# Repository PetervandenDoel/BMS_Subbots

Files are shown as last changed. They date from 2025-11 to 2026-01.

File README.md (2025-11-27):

# Battery Management System (BMS) for UBC Subbots

Custom 4-cell LiPo Battery Management System designed for the Subbots AUV.
Supports high-current discharge, full battery protection, and regulated power distribution for onboard electronics.

⸻

## Overview
	•	Designed for a 4S LiPo (Blue Robotics)
	•	Nominal: 14.8 V
	•	Max: 16.8 V
	•	Supports up to 80 A peak discharge
	•	Uses BQ76920 as the analog front end (AFE)
	•	Uses nRF54L15 as the microcontroller
	•	Generates regulated 12 V, 9 V, and 5 V rails using high-current buck regulators
	•	Low-side FET switching for discharge control
	•	Complete cell balancing, protection, and monitoring

⸻

### Battery Front End (BQ76920)
	•	Measures cell voltages (4S)
	•	Computes pack current using a Kelvin-routed shunt resistor
	•	Provides:
	•	Over-current (OCD) protection
	•	Short-circuit (SCD) protection
	•	Under-voltage and over-voltage protection
	•	Temperature monitoring (TS1)
	•	Cell balancing
	•	SRP/SRN routed as Kelvin sense lines with RC filtering
	•	PACK− and BAT− separated through the shunt resistor only

⸻

### Microcontroller (nRF54L15)
	•	Handles I²C communication with BQ76920
	•	ALERT pin used for interrupt-based event handling
	•	SWD interface exposed
	•	Powered from the regulated 3.3 V rail

⸻

## Power Regulation

### LM2596 (Pre-Regulator)
	•	Drops pack voltage down to ~5 V
	•	Used strictly to power the logic and control section of the AOZ2261NQI-11 regulators

### AOZ2261NQI-11 Buck Regulators
	•	Three independent outputs:
	•	12 V rail
	•	9 V rail
	•	5 V rail
	•	Each regulator includes:
	•	Separate AGND and PGND regions
	•	A single-point net tie back to PACK−
	•	Recommended output LC filtering
	•	Local decoupling at the VCC pin
	•	Designed to supply high peak currents needed by the AUV subsystems

⸻

## Grounding Strategy
	•	PACK− is the main high-current ground (GNDPWR)
	•	BAT− exists only for the shunt resistor and BQ76920 sense inputs
	•	AGND islands for analog and control circuits
	•	All grounds meet at a single point via net-tie:
	•	BAT− → shunt → PACK− → global ground reference
	•	Switching grounds (PGND) kept physically isolated from sensitive analog routing

⸻

## Connectors
	•	XT90 for main power input/output
	•	JST-XH for cell balance connector
	•	Multiple JST-XH headers for 12 V, 9 V, and 5 V outputs
	•	External thermistor header
	•	SWD programming header

⸻

## Protection and Sensing
	•	Low-value shunt resistor sized for 80 A peak thresholds
	•	OCD/SCD thresholds configured per BQ76920 limits
	•	RC network around SRP/SRN matches TI application notes
	•	Thermistor network matches BQ76920 TS1 recommendations
	•	Gate drive protection network included for discharge FET

⸻

### PCB Considerations
	•	LX nodes on AOZ regulators kept short and constrained
	•	Feedback resistors routed away from switching nets
	•	BQ76920 input filters placed as close as possible to pins
	•	Shunt resistor placed directly between PACK− and BAT− with symmetric Kelvin routing
	•	Output connectors isolated from analog area
	•	Power planes separated into:
	•	GNDPWR (high-current)
	•	GNDA (AFE, MCU, feedback)
	•	Tied at a single net-tie

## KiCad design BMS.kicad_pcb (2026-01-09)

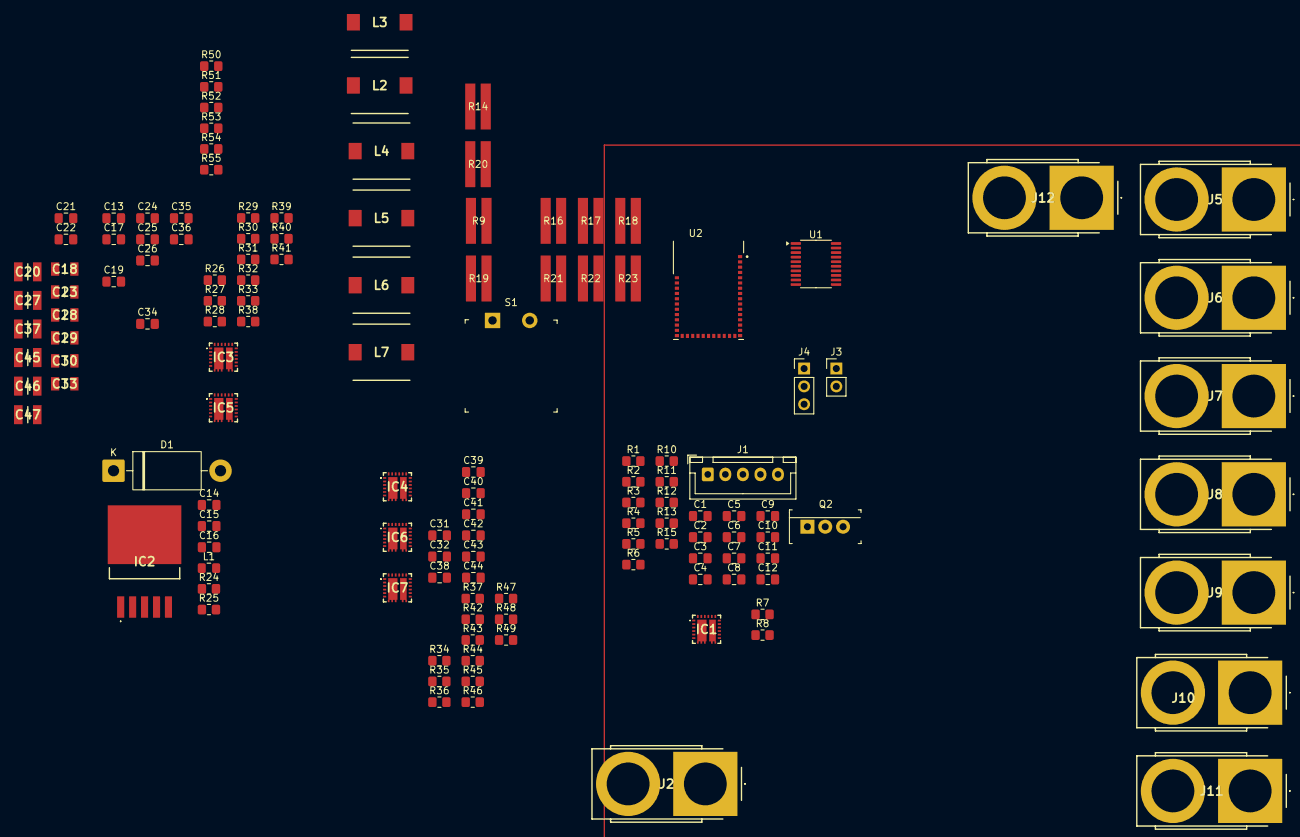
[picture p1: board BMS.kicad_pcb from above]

Board: 2 copper layers, 133 parts (0 on the bottom side), 78 nets.

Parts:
C1, C2, C3, C4, C5, C6, C12: 1u; C_0805_2012Metric_Pad1.18x1.45mm_HandSolder
C7: 10u; C_0805_2012Metric_Pad1.18x1.45mm_HandSolder
C8, C9, C10, C19, C21, C24, C31, C32, C34, C38: 100n; C_0805_2012Metric_Pad1.18x1.45mm_HandSolder
C11, C17, C26, C36, C42, C43, C44: 4u7; C_0805_2012Metric_Pad1.18x1.45mm_HandSolder
C13, C16, C25, C35, C39, C40, C41: 10n; C_0805_2012Metric_Pad1.18x1.45mm_HandSolder
C14, C22: 100u; C_0805_2012Metric_Pad1.18x1.45mm_HandSolder
C15: 220u; C_0805_2012Metric_Pad1.18x1.45mm_HandSolder
C18, C23, C28, C29, C30, C33: TMK316BBJ226ML-T; CAPC3216X190N
C20, C27, C37, C45, C46, C47: EMK325ABJ107MM-P; CAPC3225X270N
D1: 1N5822; D_DO-201AD_P15.24mm_Horizontal
IC1, IC3, IC4, IC5, IC6, IC7: AOZ2261NQI-11; AOZ2261NQI11
IC2: LM2596DSADJG
J1: Conn_01x05_Pin; JST_XH_B5B-XH-A_1x05_P2.50mm_Vertical
J2, J5, J6, J7, J8, J9, J10, J11, J12: XT90PB-F; XT90PBF
J3: Conn_01x02_Pin; PinHeader_1x02_P2.54mm_Vertical
J4: Conn_01x03_Pin; PinHeader_1x03_P2.54mm_Vertical
L1: 33u; L_0805_2012Metric_Pad1.15x1.40mm_HandSolder
L2, L3, L4, L5, L6, L7: HCM1A0805-3R3-R; INDPM8180X540N
Q2: IRLB3813PBF; TO-220-3
R1, R2, R3, R4, R5, R6, R11, R12: 100; R_0805_2012Metric_Pad1.20x1.40mm_HandSolder
R7: 4k7'; R_0805_2012Metric_Pad1.20x1.40mm_HandSolder
R8, R15: 4k7; R_0805_2012Metric_Pad1.20x1.40mm_HandSolder
R9, R14, R16, R17, R18, R19, R20, R21, R22, R23: 13m; RES_LTR100L_ROM
R10: 1M; R_0805_2012Metric_Pad1.20x1.40mm_HandSolder
R13, R29, R33, R41, R45, R47, R49, R50, R51, R52, R53, R54, R55: 10k; R_0805_2012Metric_Pad1.20x1.40mm_HandSolder
R24: 3k1; R_0805_2012Metric_Pad1.20x1.40mm_HandSolder
R25: 1k; R_0805_2012Metric_Pad1.20x1.40mm_HandSolder
R26, R31, R37, R39, R42, R43: 100k; R_0805_2012Metric_Pad1.20x1.40mm_HandSolder
R27, R34: 1.2M; R_0805_2012Metric_Pad1.20x1.40mm_HandSolder
R28, R44: 190k; R_0805_2012Metric_Pad1.20x1.40mm_HandSolder
R30, R35: 600k; R_0805_2012Metric_Pad1.20x1.40mm_HandSolder
R32, R46: 140k; R_0805_2012Metric_Pad1.20x1.40mm_HandSolder
R36, R38: 333k; R_0805_2012Metric_Pad1.20x1.40mm_HandSolder
R40, R48: 75k; R_0805_2012Metric_Pad1.20x1.40mm_HandSolder
S1: GPTS203211B; PushButton_12x12mm_THT_GPTS203211B
U1: BQ76920PW; TSSOP-20_4.4x6.5mm_P0.65mm
U2: 453-00001R; XCVR_453-00001R

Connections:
5VOUT_A: C37.2, J12.2, L5.2, R40.2
5VOUT_B: C47.2, J11.2, L7.2, R48.2
9VOUT_A: C27.2, J9.2, L3.2, R32.2
9VOUT_B: C46.2, J10.2, L6.2, R46.2
12VOUT_A: C20.2, J7.2, L2.2, R28.2
12VOUT_B: C45.2, J8.2, L4.2, R44.2
+5V: C15.1, C16.2, C17.1, C26.1, C36.1, C42.1, C43.1, C44.1, IC1.21 (VCC), IC3.21 (VCC), IC4.21 (VCC), IC5.21 (VCC), IC6.21 (VCC), IC7.21 (VCC), L1.2, R24.2, R26.1, R31.1, R37.1, R39.1, R43.1
/ALERT: U1.20 (ALERT), U2.23 (P1.04/AIN0/CLK)
/PGOOD5_A: IC5.1 (PGOOD), R39.2
/PGOOD5_B: IC7.1 (PGOOD), R43.2
/PGOOD9_A: IC3.1 (PGOOD), R31.2
/PGOOD9_B: IC6.1 (PGOOD), R42.2
/PGOOD12_A: IC4.1 (PGOOD), R37.2
/PGOOD12_B: IC1.1 (PGOOD), R26.2
/Power Distribution/FB5_A: IC5.5 (FB), R40.1, R41.2
/Power Distribution/FB5_B: IC7.5 (FB), R48.1, R49.2
/Power Distribution/FB9_A: IC3.5 (FB), R32.1, R33.2
/Power Distribution/FB9_B: IC6.5 (FB), R46.1, R47.2
/Power Distribution/FB12_A: IC1.5 (FB), R28.1, R29.2
/Power Distribution/FB12_B: IC4.5 (FB), R44.1, R45.2
/Power Distribution/LX5_A: C34.1, IC5.10 (LX_1), IC5.11 (LX_2), IC5.16 (LX_3), IC5.17 (LX_4), IC5.18 (LX_5), IC5.25 (LX_6), L5.1
/Power Distribution/LX5_B: C38.1, IC7.10 (LX_1), IC7.11 (LX_2), IC7.16 (LX_3), IC7.17 (LX_4), IC7.18 (LX_5), IC7.25 (LX_6), L7.1
/Power Distribution/LX9_A: C24.1, IC3.10 (LX_1), IC3.11 (LX_2), IC3.16 (LX_3), IC3.17 (LX_4), IC3.18 (LX_5), IC3.25 (LX_6), L3.1
/Power Distribution/LX9_B: C32.1, IC6.10 (LX_1), IC6.11 (LX_2), IC6.16 (LX_3), IC6.17 (LX_4), IC6.18 (LX_5), IC6.25 (LX_6), L6.1
/Power Distribution/LX12_A: C19.1, IC1.10 (LX_1), IC1.11 (LX_2), IC1.16 (LX_3), IC1.17 (LX_4), IC1.18 (LX_5), IC1.25 (LX_6), L2.1
/Power Distribution/LX12_B: C31.1, IC4.10 (LX_1), IC4.11 (LX_2), IC4.16 (LX_3), IC4.17 (LX_4), IC4.18 (LX_5), IC4.25 (LX_6), L4.1
/Power Distribution/OCS5_A: IC5.19 (OCS), R52.2
/Power Distribution/OCS5_B: IC7.19 (OCS), R53.2
/Power Distribution/OCS9_A: IC3.19 (OCS), R51.2
/Power Distribution/OCS9_B: IC6.19 (OCS), R54.2
/Power Distribution/OCS12_A: IC1.19 (OCS), R50.2
/Power Distribution/OCS12_B: IC4.19 (OCS), R55.2
/REGOUT: C11.1, R7.1, R8.1, U1.8 (REGOUT), U2.26 (VDD_NRF)
/RegulatorInput/Feedback: C16.1, IC2.4 (FEEDBACK), R24.1, R25.1
/RegulatorInput/Output: D1.1 (K), IC2.2 (OUTPUT), L1.1
/SCL0: R8.2, U1.5 (SCL), U2.14 (P1.03/NFC2/CLK)
/SDA0: R7.2, U1.4 (SDA), U2.15 (P1.02/NFC1)
/SRN: C9.1, C10.1, R12.1, U1.19 (SRN)
/SRP: C8.1, C10.2, R11.1, U1.18 (SRP)
/SWDIO: J4.1, U2.5 (SWDIO)
/TS1: J3.1, R13.2, R15.1, U1.6 (TS1)
/VC0: R5.1, U1.17 (VC0)
/VC1: R4.1, S1.1, U1.16 (VC1)
/VC2: R3.1, U1.15 (VC2)
/VC3: R2.1, U1.13 (VC4), U1.14 (VC3)
/VC4: R1.1, U1.12 (VC5)
BAT+: C6.1, C14.1, C18.2, C21.1, C22.1, C23.2, C28.2, C29.2, C30.2, C33.2, IC1.7 (IN_1), IC1.8 (IN_2), IC1.9 (IN_3), IC1.22 (IN_4), IC1.24 (IN_5), IC2.1 (VIN), IC3.7 (IN_1), IC3.8 (IN_2), IC3.9 (IN_3), IC3.22 (IN_4), IC3.24 (IN_5), IC4.7 (IN_1), IC4.8 (IN_2), IC4.9 (IN_3), IC4.22 (IN_4), IC4.24 (IN_5), IC5.7 (IN_1), IC5.8 (IN_2), IC5.9 (IN_3), IC5.22 (IN_4), IC5.24 (IN_5), IC6.7 (IN_1), IC6.8 (IN_2), IC6.9 (IN_3), IC6.22 (IN_4), IC6.24 (IN_5), IC7.7 (IN_1), IC7.8 (IN_2), IC7.9 (IN_3), IC7.22 (IN_4), IC7.24 (IN_5), J2.2, J5.2, J6.2, R6.1, R27.2, R30.2, R34.2, R35.2, R36.2, R38.2, U1.9 (REGSRC)
BAT-: C4.2, C5.1, C5.2, C6.2, C7.2, C8.2, C9.2, C11.2, C12.2, C21.2, C22.2, J1.1, J2.1, R5.2, R9.2, R11.2, R14.2, R16.2, R17.2, R18.2, R19.2, R20.2, R21.2, R22.2, R23.2, U1.3 (VSS)
GNDA: C13.2, C17.2, C25.2, C26.2, C35.2, C36.2, C39.2, C40.2, C41.2, C42.2, C43.2, C44.2, IC1.3 (MODE), IC1.4 (AGND), IC3.3 (MODE), IC3.4 (AGND), IC4.3 (MODE), IC4.4 (AGND), IC5.3 (MODE), IC5.4 (AGND), IC6.3 (MODE), IC6.4 (AGND), IC7.3 (MODE), IC7.4 (AGND), R29.1, R33.1, R41.1, R45.1, R47.1, R49.1, R50.1, R51.1, R52.1, R53.1, R54.1, R55.1
GNDPWR: C18.1, C20.1, C23.1, C27.1, C28.1, C29.1, C30.1, C33.1, C37.1, C45.1, C46.1, C47.1, IC1.12 (PGND_1), IC1.13 (PGND_2), IC1.14 (PGND_3), IC1.15 (PGND_4), IC3.12 (PGND_1), IC3.13 (PGND_2), IC3.14 (PGND_3), IC3.15 (PGND_4), IC4.12 (PGND_1), IC4.13 (PGND_2), IC4.14 (PGND_3), IC4.15 (PGND_4), IC5.12 (PGND_1), IC5.13 (PGND_2), IC5.14 (PGND_3), IC5.15 (PGND_4), IC6.12 (PGND_1), IC6.13 (PGND_2), IC6.14 (PGND_3), IC6.15 (PGND_4), IC7.12 (PGND_1), IC7.13 (PGND_2), IC7.14 (PGND_3), IC7.15 (PGND_4)
unnamed: C19.2, IC1.20 (BST)
unnamed: C13.1, IC1.23 (SS)
unnamed: IC1.6 (TON), R27.1
unnamed: C24.2, IC3.20 (BST)
unnamed: C25.1, IC3.23 (SS)
unnamed: IC3.6 (TON), R30.1
unnamed: C31.2, IC4.20 (BST)
unnamed: C39.1, IC4.23 (SS)
unnamed: IC4.6 (TON), R34.1
unnamed: C34.2, IC5.20 (BST)
unnamed: C35.1, IC5.23 (SS)
unnamed: IC5.6 (TON), R38.1
unnamed: C32.2, IC6.20 (BST)
unnamed: C40.1, IC6.23 (SS)
unnamed: IC6.6 (TON), R35.1
unnamed: C38.2, IC7.20 (BST)
unnamed: C41.1, IC7.23 (SS)
unnamed: IC7.6 (TON), R36.1
unnamed: C3.2, C4.1, J1.2, R4.2
unnamed: C2.2, C3.1, J1.3, R3.2
unnamed: C1.2, C2.1, J1.4, R2.2
unnamed: C1.1, J1.5, R1.2
unnamed: Q2.1 (G), R10.1, U1.1 (DSG)
unnamed: Q2.3 (S), R9.1, R10.2, R12.2, R14.1, R16.1, R17.1, R18.1, R19.1, R20.1, R21.1, R22.1, R23.1
unnamed: R13.1, S1.2
unnamed: C7.1, R6.2, U1.10 (BAT)
unnamed: C12.1, U1.7 (CAP1)
PACK-: C14.2, C15.2, D1.2 (A), IC2.3 (GROUND_1), IC2.5 (~ON/OFF), IC2.6 (GROUND_2), J3.2, J4.3, J5.1, J6.1, J7.1, J8.1, J9.1, J10.1, J11.1, J12.1, Q2.2 (D), R15.2, R25.2, U2.1 (GND), U2.16 (GND), U2.27 (GND), U2.39 (GND)

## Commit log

2026-01-08 Added 3.3u inductors to schematic and PCB file, created project specific library folder and added inductor model to it
2026-01-08 Added output and input caps for buck converters into the schematic. Added components into the project specific library.
    [BMS.kicad_pcb, PD.kicad_sch]
2026-01-09 Changed RTon values to get reasonable osscilation frequencies for all the buck converters, added 10K current limit resistors to all the OCS pins, adjusted some net names to be different for the two b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
    [BMS.kicad_pcb, PD.kicad_sch]
2026-01-09 Added A and Bonto the all the net labels and sheet outputs for the pairs of buck converters. Moved the XT90 connector for the battery input to the connectors sectionof the main sheet and renamed the 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
    [BMS.kicad_pcb, BMS.kicad_sch, PD.kicad_sch]
2026-01-09 Added note to change the ground of the Nordic MCU to the battery minus terminal rather than the ground of the rest of the sub. The power to the nordic won't be measured by coulomb counting, but I arg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
    [BMS.kicad_sch]
2026-01-09 Added EN and Pgood pins for the second set of buck converters to the NRF
    [BMS.kicad_sch, MCU.kicad_sch]
2026-01-25 dealing with merge issues
    [BMS.kicad_sch]
